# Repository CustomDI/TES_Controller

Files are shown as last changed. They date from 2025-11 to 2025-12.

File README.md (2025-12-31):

# TES Controller Serial Command Reference

This document describes every serial command exposed by the TES Controller
firmware found in `TES_Controller/TES_Controller.ino`. Use it as the definitive
reference when interacting with the board over a USB serial connection or when
building higher-level host tooling.

## Serial Session Basics

- **Port settings:** 115200 baud, 8 data bits, no parity, 1 stop bit, no flow
  control (115200 8N1).
- **Line endings:** Commands are terminated with a newline (`\n`) or carriage
  return + newline (`\r\n`). The command parser is case-insensitive for the
  top-level tokens (`LNA`, `TES`, `DAC`, `HELP`) but subcommand keywords should
  be supplied exactly as shown below.
- **Channel numbering:** Firmware expects one-based channel indices.
  - TES channels: `1` – `12`
  - LNA channels: `1` – `2`
- **Targets:** Whenever a command requires a LNA target path, use literal
  `GATE` or `DRAIN`.

## Response Format

Every command returns a YAML packet terminated by a blank line. Successful
operations use:

```yaml
---
status: ok
result:
  command: <NAME>
  ... additional key/value data ...
```

Failures (invalid parameters, I²C errors, etc.) use:

```yaml
---
status: error
result:
  error: "<SYMBOLIC_ERROR>"
  code: <numeric_status>
  message: "<human readable context>"
```

Keys and numeric ranges mentioned below mirror the firmware exactly.

## Command Tree Overview

| Top-Level | Syntax Skeleton | Purpose |
|---|---|---|
| `HELP` | `HELP` | List every available command and subcommand. |
| `DAC`  | `DAC <SUBCOMMAND> [...]` | Control the base flux-ramp DAC. |
| `LNA`  | `LNA <channel> <GATE\|DRAIN> <SUBCOMMAND> [...]` | Inspect or tune LNA DACs and telemetry. |
| `TES`  | `TES <channel> <SUBCOMMAND> [...]` | Inspect or tune TES drive outputs and telemetry. |

The sections below expand each subcommand, including argument ranges and the
keys returned in `result`.

## HELP

```
HELP
```

Prints a tree of all commands and their brief descriptions. No YAML payload is
returned; the output is plain text generated by the StaticSerialCommands
library.

## DAC Commands

Top-level syntax: `DAC <SUBCOMMAND> [...]`

| Subcommand | Syntax | Description | Response keys |
|---|---|---|---|
| `SET` | `DAC SET <value>` | Write channel A of the MCP4728 flux-ramp DAC. Valid `value` range is `0` – `1024`; this value is offset to a valid range. | `command: "DAC_SET"`, `value` (echo), `message` |
| `GET` | `DAC GET` | Read the current value programmed into channel A. | `command: "DAC_GET"`, `value`, `message` |

## LNA Commands

Top-level syntax: `LNA <channel> <GATE|DRAIN> <SUBCOMMAND> [...]`

- `channel`: integral, `1` – `2`
- `target`: literal `GATE` or `DRAIN`

| Subcommand | Syntax | Description | Response keys |
|---|---|---|---|
| `GET` | `LNA <ch> <target> GET` | Aggregate status dump of the selected path. | `command: "LNA_GET"`, `channel`, `target`, `dac_value`, `enabled`, `shunt_mV`, `bus_V`, `current_mA`, `power_mW` |
| `ENABLE` | `LNA <ch> <target> ENABLE` | Assert the enable line. | `command: "LNA_ENABLE"`, `channel`, `target`, `enabled: "true"` |
| `DISABLE` | `LNA <ch> <target> DISABLE` | De-assert the enable line. | `command: "LNA_DISABLE"`, `channel`, `target`, `enabled` (currently returns the string `"true"`; treat the command success as authoritative) |
| `SETMA` | `LNA <ch> <target> SETMA <current_mA>` | Closed-loop search to achieve the requested current. `current_mA` range: `0` – `64`. | `command: "LNA_SET"`, `channel`, `target`, `current_mA`, `dac_value` |
| `SETV` | `LNA <ch> <target> SETV <voltage_V>` | Closed-loop search to achieve the requested voltage. Range: `0` – `5` volts. | `command: "LNA_SET"`, `channel`, `target`, `voltage_V`, `dac_value` |
| `SETDAC` | `LNA <ch> <target> SETDAC <raw>` | Write a raw 12-bit DAC code (0 – 4095). | `command: "LNA_SET"`, `channel`, `target`, `value` |
| `SHUNT` | `LNA <ch> <target> SHUNT` | Read the INA228 shunt voltage in millivolts. | `command: "LNA_SHUNT"`, `channel`, `target`, `shunt_mV` |
| `BUS` | `LNA <ch> <target> BUS` | Read the bus voltage in volts. | `command: "LNA_BUS"`, `channel`, `target`, `bus_V` |
| `CURRENT` | `LNA <ch> <target> CURRENT` | Read the calculated current in milliamps. | `command: "LNA_CURRENT"`, `channel`, `target`, `current_mA` |
| `POWER` | `LNA <ch> <target> POWER` | Read the calculated power in milliwatts. | `command: "LNA_POWER"`, `channel`, `target`, `power_mW` |

Errors during any LNA operation return an `error` symbol such as
`"LNA_SET_ERROR"`, `"LNA_BUS_READ_ERROR"`, etc., along with the low-level I²C
status code (`code`).

## TES Commands

Top-level syntax: `TES <channel> <SUBCOMMAND> [...]`

- `channel`: integral, `1` – `12`

| Subcommand | Syntax | Description | Response keys |
|---|---|---|---|
| `GET` | `TES <ch> GET` | Aggregate status dump of the TES channel. | `command: "TES_GET"`, `channel`, `enabled`, `tca_bits`, `shunt_mV`, `bus_V`, `current_mA`, `power_mW` |
| `ENABLE` | `TES <ch> ENABLE` | Enable the TES output stage. | `command: "TES_ENABLE"`, `channel`, `enabled: "true"` |
| `DISABLE` | `TES <ch> DISABLE` | Disable the TES output stage. | `command: "TES_DISABLE"`, `channel`, `enabled: "false"` |
| `SET` | `TES <ch> SET <current_mA>` | Closed-loop current search (0 – 20 mA). Returns the final DAC state used. | `command: "TES_SET"`, `channel`, `current_mA` (achieved), `tca_bits` |
| `SETINT` | `TES <ch> SETINT <bits>` | Write raw 20-bit TCA output as an integer (`0` – `0xFFFFF`). | `command: "TES_SETINT"`, `channel`, `tca_bits` |
| `SETHEX` | `TES <ch> SETHEX <hex_value>` | Write raw 20-bit TCA output in hexadecimal (`00000` – `FFFFF`). | `command: "TES_SETHEX"`, `channel`, `tca_bits` |
| `BIT` | `TES <ch> BIT` | Read the current TCA output state. | `command: "TES_BITS"`, `channel`, `tca_bits` |
| `INC` | `TES <ch> INC <delta>` | Increase the TCA output by `delta` counts (0 – `0xFFFFF`). | `command: "TES_INC"`, `channel`, `delta`, `tca_bits` |
| `DEC` | `TES <ch> DEC <delta>` | Decrease the TCA output by `delta` counts. | `command: "TES_DEC"`, `channel`, `delta`, `tca_bits` |
| `SHUNT` | `TES <ch> SHUNT` | Measure shunt voltage (mV). | `command: "TES_SHUNT"`, `channel`, `shunt_mV` |
| `BUS` | `TES <ch> BUS` | Measure bus voltage (V). | `command: "TES_BUS"`, `channel`, `bus_V` |
| `CURRENT` | `TES <ch> CURRENT` | Measure TES current (mA). | `command: "TES_CURRENT"`, `channel`, `current_mA` |
| `POWER` | `TES <ch> POWER` | Measure TES power (mW). | `command: "TES_POWER"`, `channel`, `power_mW` |

All TES error responses follow the same structure with symbols like
`"TES_SET_CURRENT_ERROR"`, `"TES_TCA_READ_ERROR"`, etc.

## Notes & Tips

- **Search-based setters:** `LNA SETMA`, `LNA SETV`, and `TES SET` perform
  iterative searches using the underlying driver convenience routines. The
  returned `current_mA`, `voltage_V`, or `tca_bits` represent the post-search
  state actually achieved.
- **Raw DAC writes:** `SETDAC`, `SETINT`, and `SETHEX` bypass any search logic
  and immediately write the specified code. Take care not to exceed the valid
  ranges—values outside the ranges listed above are rejected with
  `status: error`.
- **Telemetry units:**
  - Shunt voltages are reported in millivolts (`mV`).
  - Bus voltages are reported in volts (`V`).
  - Currents are reported in milliamps (`mA`).
  - Powers are reported in milliwatts (`mW`).
- **Error codes:** The numeric `code` field in an error response comes directly
  from the driver status return (typically an I²C error byte). A non-zero code
  indicates the call did not reach the requested hardware state.

With this reference you can script direct interactions with the firmware, build
custom tooling, or simply verify that higher-level software layers send the
expected traffic.

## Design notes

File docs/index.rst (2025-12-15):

TES Controller Documentation
============================

Welcome to the TES Controller Python client documentation!

The TES Controller is a Python interface for controlling Transition Edge Sensor
(TES) and Low Noise Amplifier (LNA) hardware via serial communication.

.. toctree::
   :maxdepth: 2
   :caption: Contents:

   installation
   getting-started
   usage
   examples
   api
   hardware-guide

Key Features
------------

- **Simple API**: High-level helpers for TES, LNA, and flux ramp control
- **Flexible Channel Selection**: Address individual channels or batches with one call
- **Typed Interfaces**: Rich type hints for IDE autocomplete and static analysis
- **Comprehensive Error Handling**: Deterministic `CommandError` hierarchy for driver faults
- **Config Driven**: Optional YAML configuration keeps serial parameters out of code
- **Context Manager Support**: Clean resource management with ``with`` statements

Quick Start
-----------

.. code-block:: python

   from tes_controller import DeviceController

   # Load settings from YAML
   with DeviceController.from_config('python/config.yaml') as ctrl:
      ctrl.tes_enable(channel=[1, 2, 3])
      ctrl.tes_set_current(channel=[1, 2, 3], current_mA=[5.0, 4.5, 4.0])
      reading = ctrl.tes_get_all(channel=1)
      print(reading)

   # Or construct manually when you need to override serial defaults
   ctrl = DeviceController(port='/dev/ttyACM0', baud=115200, timeout=1.0)
   try:
      ctrl.tes_set_current(current_mA=5.0)
   finally:
      ctrl.close()

Indices and tables
==================

* :ref:`genindex`
* :ref:`modindex`
* :ref:`search`

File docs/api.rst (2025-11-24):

API Reference
=============

Top-level Package
-----------------

.. automodule:: tes_controller
   :members:
   :undoc-members:
   :show-inheritance:

Device Controller
-----------------

.. automodule:: tes_controller.controller
   :members:
   :undoc-members:
   :show-inheritance:
   :exclude-members: DeviceController

.. autoclass:: tes_controller.controller.DeviceController
   :members:
   :show-inheritance:

Drivers
-------

.. automodule:: tes_controller.drivers
   :members:
   :undoc-members:
   :show-inheritance:

Serial Client
-------------

.. automodule:: tes_controller.serial_client
   :members:
   :undoc-members:
   :show-inheritance:

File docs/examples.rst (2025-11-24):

Examples
========

The snippets below illustrate complete, runnable patterns built on top of the
high-level :class:`tes_controller.controller.DeviceController` API.

Basic Example
-------------

.. code-block:: python

   from tes_controller import DeviceController
   from tes_controller.drivers import CommandError

   with DeviceController.from_config('python/config.yaml') as ctrl:
       try:
           reading = ctrl.tes_get_all(channel=1)
           print(f"Channel 1 state: {reading}")

           ctrl.tes_set_current(channel=1, current_mA=5.0)
           ctrl.tes_enable(channel=1)
       except CommandError as exc:
           print(f"Hardware command failed: {exc}")

Multi-Channel Operations
------------------------

.. code-block:: python

   from tes_controller import DeviceController

   with DeviceController.from_config('python/config.yaml') as ctrl:
       all_data = ctrl.tes_get_all()
       for index, data in enumerate(all_data, start=1):
           print(f"Channel {index}: {data}")

       ctrl.tes_set_current(current_mA=5.0)

       ctrl.tes_set_current(
           current_mA=[1.0, 2.0, 3.0, 4.0, 5.0, 6.0]
       )

       ctrl.tes_enable(channel=[1, 3, 5])

Current Sweep
-------------

.. code-block:: python

   import time
   from tes_controller import DeviceController

   with DeviceController.from_config('python/config.yaml') as ctrl:
       channel = 1
       for target in [0.5, 1.0, 1.5, 2.0, 2.5]:
           ctrl.tes_set_current(channel=channel, current_mA=target)
           time.sleep(0.1)
           readback = ctrl.tes_get_current(channel=channel)
           print(f"Commanded {target:.2f} mA -> {readback.get('current_mA', 'N/A')} mA")

Batch Configuration
-------------------

.. code-block:: python

   from tes_controller import DeviceController

   configuration = {
       1: {"current_mA": 5.0, "enabled": True},
       2: {"current_mA": 3.5, "enabled": True},
       3: {"current_mA": 4.2, "enabled": False},
       4: {"current_mA": 6.1, "enabled": True},
       5: {"current_mA": 2.8, "enabled": True},
       6: {"current_mA": 5.5, "enabled": False},
   }

   with DeviceController.from_config('python/config.yaml') as ctrl:
       for channel, settings in configuration.items():
           ctrl.tes_set_current(channel=channel, current_mA=settings["current_mA"])
           if settings["enabled"]:
               ctrl.tes_enable(channel=channel)
           else:
               ctrl.tes_disable(channel=channel)

       for channel in configuration:
           print(f"Channel {channel}: {ctrl.tes_get_all(channel=channel)}")

LNA Configuration
-----------------

.. code-block:: python

   from tes_controller import DeviceController

   with DeviceController.from_config('python/config.yaml') as ctrl:
       ctrl.lna_set_dac(target='GATE', value=[0x4000, 0x4500, 0x5000, 0x5500, 0x6000, 0x6500])
       ctrl.lna_set_dac(channel=[1, 2, 3], target='DRAIN', value=0x8000)

       ctrl.lna_enable(target='GATE')
       ctrl.lna_enable(channel=[1, 2, 3], target='DRAIN')

       for channel in range(1, 7):
           gate = ctrl.lna_get_all(channel=channel, target='GATE')
           drain = ctrl.lna_get_all(channel=channel, target='DRAIN')
           print(f"Channel {channel}: gate={gate} drain={drain}")

       ctrl.lna_set_voltage(channel=1, target='GATE', voltage_V=1.2)
       ctrl.lna_set_current(target='GATE', current_mA=[0.5, 1.0, 1.5, 2.0, 2.5, 3.0])

Flux Ramp DAC
-------------

.. code-block:: python

   from tes_controller import DeviceController

   with DeviceController.from_config('python/config.yaml') as ctrl:
       ctrl.flux_ramp_set(0x8000)
       print(ctrl.flux_ramp_get())

Data Acquisition
----------------

.. code-block:: python

   import csv
   import time
   from tes_controller import DeviceController

   with DeviceController.from_config('python/config.yaml') as ctrl:
       ctrl.tes_enable()
       ctrl.tes_set_current(current_mA=5.0)

       sample_rate_hz = 10
       duration_sec = 5
       interval = 1.0 / sample_rate_hz

       with open('tes_data.csv', 'w', newline='') as handle:
           writer = csv.writer(handle)
           header = ['time_s']
           header.extend([f'ch{idx}_current_mA' for idx in range(1, ctrl.num_tes + 1)])
           header.extend([f'ch{idx}_power_mW' for idx in range(1, ctrl.num_tes + 1)])
           writer.writerow(header)

           start = time.time()
           while time.time() - start < duration_sec:
               elapsed = time.time() - start
               currents = ctrl.tes_get_current()
               powers = ctrl.tes_get_power()
               row = [elapsed]
               row.extend([entry.get('current_mA', 0.0) for entry in currents])
               row.extend([entry.get('power_mW', 0.0) for entry in powers])
               writer.writerow(row)
               time.sleep(interval)

Robust Error Handling
---------------------

.. code-block:: python

   import time
   from tes_controller import DeviceController
   from tes_controller.drivers import CommandError

   def safe_set_current(ctrl, channel, current_mA, attempts=3):
       for attempt in range(1, attempts + 1):
           try:
               ctrl.tes_set_current(channel=channel, current_mA=current_mA)
               time.sleep(0.1)
               actual = ctrl.tes_get_current(channel=channel)
               print(f"Channel {channel}: target {current_mA} mA -> actual {actual.get('current_mA', 'N/A')} mA")
               return True
           except CommandError as exc:
               print(f"Attempt {attempt}/{attempts} failed: {exc}")
       return False

   with DeviceController.from_config('python/config.yaml') as ctrl:
       for channel in range(1, ctrl.num_tes + 1):
           safe_set_current(ctrl, channel, current_mA=5.0)

Complete Workflow Script
------------------------

.. code-block:: python

   import argparse
   import time
   from tes_controller import DeviceController
   from tes_controller.drivers import CommandError

   def initialize(ctrl):
       ctrl.tes_disable()
       ctrl.tes_set_current(current_mA=0.0)
       ctrl.lna_disable(target='GATE')
       ctrl.lna_disable(target='DRAIN')
       ctrl.lna_set_dac(target='GATE', value=0x0000)
       ctrl.lna_set_dac(target='DRAIN', value=0x0000)

   def run_profile(ctrl, profile):
       ctrl.tes_set_current(current_mA=profile['tes_current'])
       ctrl.tes_enable(channel=profile['tes_channels'])
       ctrl.lna_set_dac(target='GATE', value=profile['lna_gate'])
       ctrl.lna_enable(target='GATE')
       time.sleep(profile.get('settling_time', 1.0))
       return ctrl.tes_get_all()

   def shutdown(ctrl):
       ctrl.tes_disable()
       ctrl.lna_disable(target='GATE')
       ctrl.lna_disable(target='DRAIN')

   def main():
       parser = argparse.ArgumentParser(description='TES Controller workflow')
       parser.add_argument('--config', default='python/config.yaml')
       args = parser.parse_args()

       try:
           with DeviceController.from_config(args.config) as ctrl:
               initialize(ctrl)
               profiles = [
                   {
                       'tes_current': 5.0,
                       'tes_channels': [1, 2, 3],
                       'lna_gate': 0x8000,
                       'settling_time': 1.0,
                   },
                   {
                       'tes_current': 7.5,
                       'tes_channels': [4, 5, 6],
                       'lna_gate': 0xA000,
                       'settling_time': 1.0,
                   },
               ]

               for index, profile in enumerate(profiles, start=1):
                   print(f"\n=== Profile {index}/{len(profiles)} ===")
                   result = run_profile(ctrl, profile)
                   print(result)

               shutdown(ctrl)
       except CommandError as exc:
           print(f"Hardware error: {exc}")
       except Exception as exc:
           print(f"Unexpected error: {exc}")

   if __name__ == '__main__':
       main()

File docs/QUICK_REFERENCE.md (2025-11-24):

# TES Controller Quick Reference

## Installation

```bash
pip install -r python/requirements.txt
cp python/config_example.yaml python/config.yaml
```

## Basic Pattern

```python
from tes_controller import DeviceController

with DeviceController.from_config('python/config.yaml') as ctrl:
    ctrl.tes_enable(channel=1)
    ctrl.tes_set_current(channel=1, current_mA=5.0)
    print(ctrl.tes_get_all(channel=1))
```

## Channel Selection Cheatsheet

| Call | Description | Return Type |
|---|---|---|
| `ctrl.tes_get_all(channel=1)` | Single channel | `dict` |
| `ctrl.tes_get_all(channel=[1, 3, 5])` | Subset of channels | `list[dict]` |
| `ctrl.tes_get_all()` | All channels | `list[dict]` |
| `ctrl.tes_set_current(current_mA=5.0)` | Same value on all channels | `list[dict]` |
| `ctrl.tes_set_current(channel=[1, 3], current_mA=[1.0, 2.0])` | Pair channel list with value list | `list[dict]` |

## TES Helpers

```python
ctrl.tes_set_current(channel=1, current_mA=5.0)
ctrl.tes_inc_current(channel=1, delta=100)
ctrl.tes_dec_current(channel=1, delta=50)
ctrl.tes_set_bits(channel=1, value=0x80000)
ctrl.tes_get_current(channel=1)
ctrl.tes_get_power(channel=1)
```

## LNA Helpers

Always supply `target='GATE'` or `target='DRAIN'`.

```python
ctrl.lna_set_dac(channel=1, target='GATE', value=0x8000)
ctrl.lna_set_dac(channel=1, target='GATE', value=1.2)    # physical units
ctrl.lna_enable(target='GATE')
ctrl.lna_disable(channel=[1, 2, 3], target='GATE')
ctrl.lna_set_voltage(channel=1, target='GATE', voltage_V=1.2)
ctrl.lna_set_current(target='GATE', current_mA=[0.5, 1.0, 1.5, 2.0, 2.5, 3.0])
```

## Flux Ramp DAC

```python
ctrl.flux_ramp_set(0x8000)
ctrl.flux_ramp_get()
```

## Error Handling

```python
from tes_controller.drivers import CommandError

try:
    ctrl.tes_set_current(channel=1, current_mA=5.0)
except CommandError as exc:
    print(f"Hardware command failed: {exc}")
```

## CLI Snippets

```bash
# Build documentation
make -C docs html

# Live rebuild during authoring
sphinx-autobuild docs docs/_build/html
```

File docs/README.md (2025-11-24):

# TES Controller Documentation

This directory contains the Sphinx authoring environment for the TES Controller
project.

## 📚 Contents

### reStructuredText pages
- `index.rst` – Landing page and master ToC
- `installation.rst` – Platform-specific setup
- `getting-started.rst` – Day-one workflow guide
- `usage.rst` – Recipes and quick snippets
- `examples.rst` – End-to-end scripts
- `api.rst` – Autogenerated API reference

### Helper docs
- `README.md` – You are here
- `DOCUMENTATION_SETUP.md` – Deployment walkthrough
- `QUICK_REFERENCE.md` – One-page API cheat sheet

### Configuration & tooling
- `conf.py` – Sphinx configuration (autodoc, napoleon, type hints)
- `requirements.txt` – Doc build dependencies
- `Makefile` / `make.bat` – Build helpers (Unix/Windows)
- `_static/` – Custom static assets
- `.nojekyll` – Ensures nested directories are served by GitHub Pages

## 🚀 Build Locally

```bash
pip install -r docs/requirements.txt
make -C docs html
```

Open `docs/_build/html/index.html` in your browser when the build finishes.

### Clean & rebuild

```bash
make -C docs clean html
```

### Live reload during authoring

```bash
pip install sphinx-autobuild
sphinx-autobuild docs docs/_build/html
```

## 🌐 Publish Options

### GitHub Pages
1. Enable Pages for the repository and choose the `docs/` folder as the source.
2. Copy `docs/_build/html` into `docs/` (or automate via GitHub Actions).
3. Commit and push – GitHub Pages redeploys automatically.

### Read the Docs (optional)
1. Log in at <https://readthedocs.org/> with your GitHub account.
2. Import the repository; RTD auto-detects `docs/conf.py`.
3. Trigger a build to publish at `https://<project>.readthedocs.io/`.

## 🛠️ Updating Content
- Add new pages → create `docs/new-page.rst`, reference it in `index.rst`, rebuild.
- Refresh API docs → update Python docstrings and rerun `make -C docs html`.
- Ship new examples → edit `docs/examples.rst` and ensure scripts execute cleanly.

## ❗ Troubleshooting

| Issue | Resolution |
|---|---|
| `ModuleNotFoundError: tes_controller` | Run builds from repo root; confirm `conf.py` manipulates `sys.path`. |
| Missing CSS/JS on GitHub Pages | Ensure `.nojekyll` is present and assets were copied. |
| Sphinx warnings | Run `make -C docs clean html` and address reported issues. |

## 📎 Resources
- [Sphinx documentation](https://www.sphinx-doc.org/)
- [Read the Docs guide](https://docs.readthedocs.io/)
- [reStructuredText primer](https://www.sphinx-doc.org/en/master/usage/restructuredtext/basics.html)

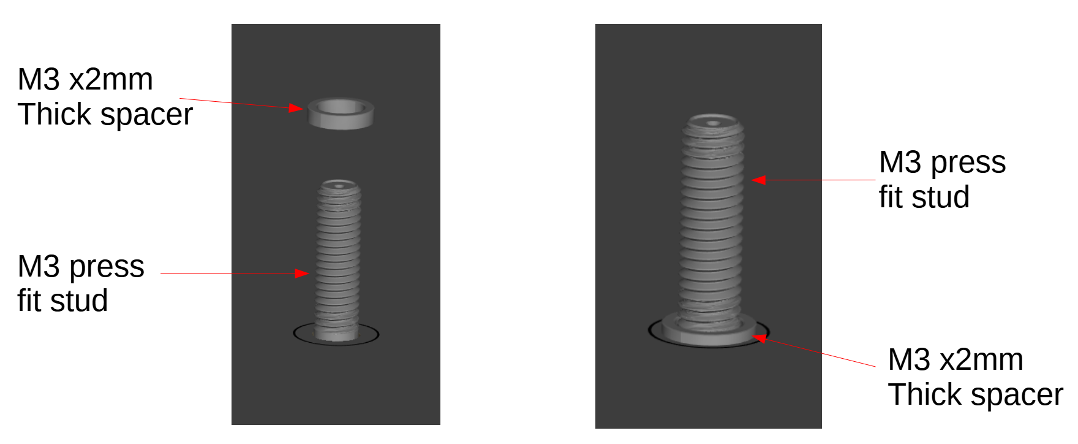
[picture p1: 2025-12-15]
docs/_static/hardware-pictures/spacers.png

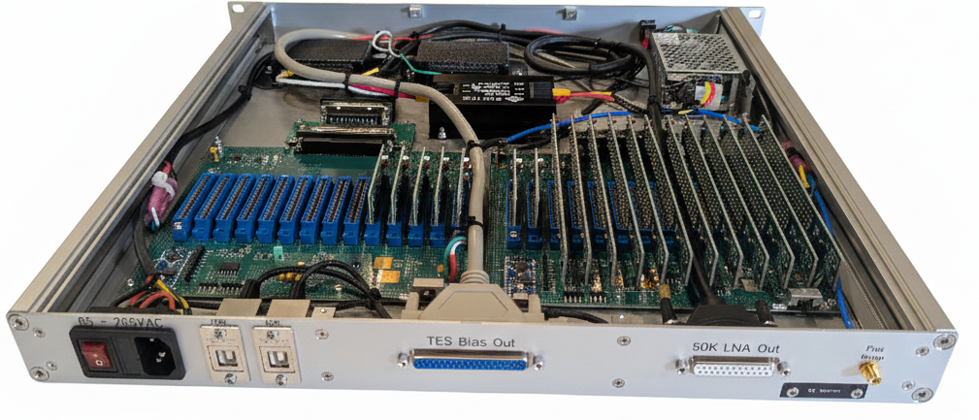
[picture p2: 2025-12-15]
docs/_static/hardware-pictures/TES_Bias_System_side_2.png

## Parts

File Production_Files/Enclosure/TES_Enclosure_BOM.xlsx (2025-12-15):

Vendor | Link | Category | Descriptor | Part # | Price | Quantity | # Spare(s) | Total Price | Note
Front Panel Express | Contact and Pay | Payment | Front/Back panel/Housing profile | N/A |  | 1 | 0 | $0.00
SendCutSend | https://invoice.sendcutsend.com/urhwne3jqfz8 | Payment Link | Rest of enclosure | N/A | $373.56 | 1 | 0 | $373.56
McMaster | https://www.mcmaster.com/9290T12/ | Electronic Hardware | Bus bar | 9290T12 | $27.11 | 2 | 0 | $54.22
McMaster | https://www.mcmaster.com/9290T25/ | Electronic Hardware | Bus bar cover | 9290T25 | $19.80 | 2 | 0 | $39.60
Digikey | https://www.digikey.com/en/products/detail/tdk-lambda/CUT35-522-A/6874069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 | Electronic Hardware | Power Supply | CUT35-522/A | $50.41 | 1 | 0 | $50.41
Digikey | https://www.digikey.com/en/products/detail/cui-inc/VFM-15C/2294930 | Electronic Hardware | Line Filter | VFM-15C | $47.83 | 1 | 0 | $47.83
Amazon | https://www.amazon.com/Kentek-Extension-Connector-Printer-Network/dp/B07KVC9C21 | Cable | DSUB 37 M to F | KT-DB37-MF-3FT | $16.74 | 1 | 1 | $33.48
Amazon | https://www.amazon.com/Female-Extension-Different-Colored-double-shielded/dp/B092QV8DGK | Cable | DSUB 25 M to F |  | $11.99 | 1 | 1 | $23.98
Amazon | https://www.amazon.com/Durable-Braided-Android-Charging-Samsung/dp/B09XK4JDBJ | Cable | Right angle 1ft micro usb (3 pack) | 1Ft-RA-MicroUSB-3P | $7.99 | 1 | 0 | $7.99
Digikey | https://www.digikey.com/en/products/detail/mini-circuits/086-18SBSMR/20526752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 | Cable | Flux ramp SMA cable | 086-18SBSMR+ | $31.03 | 1 | 0 | $31.03
Amazon | https://www.amazon.com/C2G-03130-Universal-Power-Cord/dp/B0000510ZO | Cable | 3 prong power cable |  | $4.95 | 1 | 0 | $4.95
Amazon | https://www.amazon.com/gp/product/B0899V8XH8?smid=A2ZDGCOOU4F0SF&psc=1 | Enclosure Fittings | AC Fused Socket with Switch (Rear Panel) | SM487-C14-Switch-2PCS | $16.99 | 1 | 0 | $16.99
Digikey | https://www.digikey.com/en/products/detail/l-com/ECF504-BA/21288387 | Enclosure Fittings | Adapter Connector USB-B (USB TYPE-B), Receptacle To USB-A (USB TYPE-A), Receptacle Panel Mount, Flange | ECF504-BA | $4.86 | 2 | 1 | $14.58
Digikey | https://www.digikey.com/en/products/detail/cit-relay-and-switch/RA1122XCG/12418854 | Enclosure Fittings | Rocker Switch SPST 15A (AC) 125 V Panel Mount, Snap-In | RA1122XCG | $1.66 | 1 | 1 | $3.32
Mcmaster | https://www.mcmaster.com/91115A505/ | Enclosure Fittings | DSUB standoffs for FP | 91115A505 | $1.97 | 4 | 2 | $11.82 | This is optional. This connection between the DSUB cables on either side of the panel should be sturdy enough . The standoff listed here is our best guess at the length to mate
Mcmaster | https://www.mcmaster.com/94868A038/ | Hardware | Busbar nuts | 94868A038 | $1.70 | 4 | 2 | $10.20
Mcmaster | https://www.mcmaster.com/97258A101/ | Hardware | M3 square nuts (50 pack). Slide these into corner extrusions to secure bottom and top panels to the sides | 97258A101 | $7.14 | 1 | 0 | $7.14
Isel-usa | https://www.isel-us.com/enclosure-profiles/16x18-extrusion-enclosure-corner-profile | Enclosure | 16x18-extrusion-enclosure-corner-profile. Enclosure corners. Need to be cut to equal the height of the panel (445mm) | G123020_1000 |  |  |  | $0.00
Mcmaster | https://www.mcmaster.com/90116a147/ | Hardware | Busbar cover screws: M3 4mm | 90116A147 | $15.71 | 1 |  | $15.71
Amazon | https://www.amazon.com/Swpeet-Aluminum-Assortment-Standoff-Unthreaded/dp/B0DNF9ZYY6 | Hardware | spacers for mounting plate | B0DNF9ZYY6 | $17.99 | 2 |  | $35.98
Front Panel Express | https://shop.frontpanelexpress.com/#Products | Hardware | L brackets for lid and bottom panel (12 pack) | GGWS0113 | $35.00 | 1 | 0 | $35.00 | Only 8 are necessary
Mcmaster | https://www.mcmaster.com/95844A627/ | Hardware | M4.8 machine screws for mounting housing profiles into Front and back panels | 95844A627 | $7.25 | 1 | 0 | $7.25
Mcmaster | https://www.mcmaster.com/92000A114/ | Hardware | M3 x 5mm pan head screws for L-brackets, some enclosure fittings and lid | 92000A114 | $5.45 | 1 |  | $5.45
Mcmaster | https://www.mcmaster.com/90576A102/ | Hardware | M3 locknuts for top of mounting plate | 90576A102 | $5.08 | 1 |  | $5.08
Amazon | https://a.co/d/gfr9Ptf | Electronic Hardware | Electrical Insulating Adhesive Paper 200mm(7.9in) Width 3m Length 0.2mm Thickness Self Adhesive Battery Pack Insulator Gasket for 18650 21700 26650 Battery Pack, Green | B0CJHW8JVR | $14.99 | 1 |  | $14.99
Mcmaster | https://www.mcmaster.com/93115K871/ | Hardware | Enclosure feet
Digikey | https://www.digikey.com/en/products/detail/jst-sales-america-inc/VHR-5N/608627 | Cable | Connector for power supply to Line filter | VHR-5N | $0.14 | 1 |  | $0.14
Digikey | https://www.digikey.com/en/products/detail/jst-sales-america-inc/ASVHSVH16K305/6009483 | Cable | cable with pre-crimped fittings for VHR-5N connector (power supply) | ASVHSVH16K305 | $0.86 | 3 |  | $2.58
 |  |  |  |  |  |  |  | $0.00
 |  |  |  |  |  |  |  | $0.00
 |  |  |  |  |  |  |  | $0.00
 |  |  |  |  |  |  |  | $0.00
 |  |  |  |  |  |  |  | $0.00
 |  |  |  |  |  |  |  | $0.00
 |  |  |  |  |  |  |  | $0.00
 |  |  |  |  |  |  |  | $0.00
 |  |  |  |  |  |  |  | $0.00
 |  |  |  |  |  |  |  | $0.00
 |  |  |  |  |  |  |  | $0.00
 |  |  |  |  |  |  |  | $0.00
 |  |  |  |  |  |  |  | $0.00
 |  |  |  |  |  |  |  | $0.00
 |  |  |  |  |  |  |  | $0.00
 |  |  |  |  |  |  |  | $0.00
 |  |  |  |  |  |  |  | $0.00
 |  |  |  |  |  |  |  | $0.00
 |  |  |  |  |  |  |  | $0.00
 |  |  |  |  |  |  |  | $0.00
 |  |  |  |  |  |  |  | $0.00
 |  |  |  |  |  |  |  | $0.00
 |  |  |  |  |  |  |  | $0.00
 |  |  |  |  |  |  |  | $0.00
 |  |  |  |  |  |  |  | $0.00
 |  |  |  |  |  |  |  | $0.00
 |  |  |  |  |  |  |  | $0.00
 |  |  |  |  |  |  |  | $0.00

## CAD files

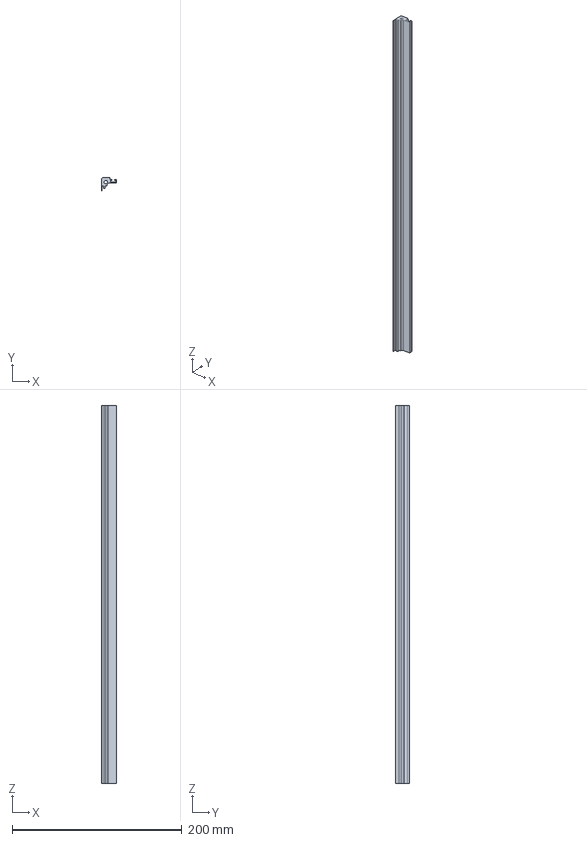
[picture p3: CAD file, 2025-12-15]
Production_Files/Enclosure/HousingProfile2_445mm.step
18.0 x 16.0 x 444.9 mm

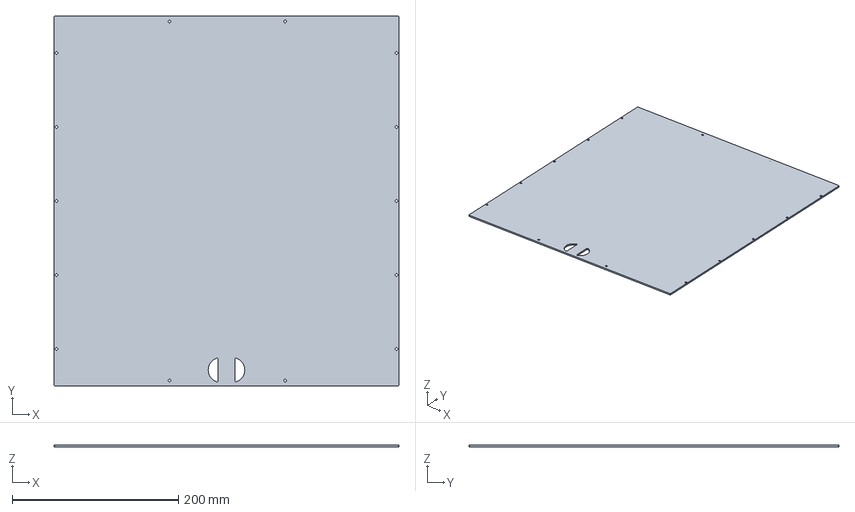
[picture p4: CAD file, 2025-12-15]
Production_Files/Enclosure/TESbias_Top.stp
415.0 x 445.0 x 2.50 mm

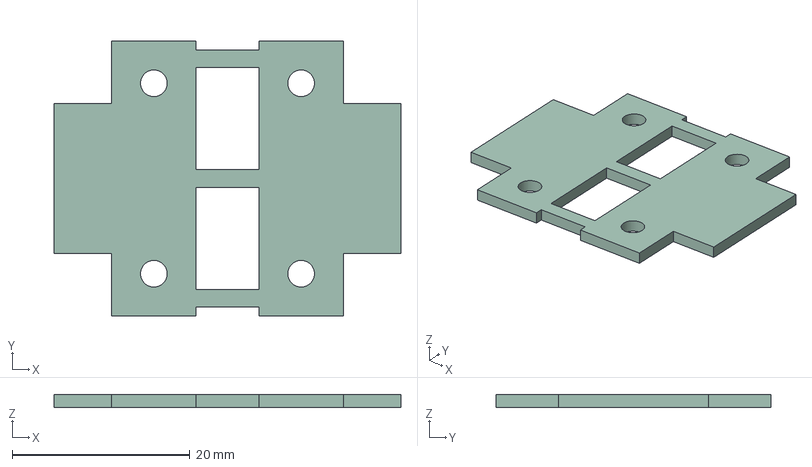
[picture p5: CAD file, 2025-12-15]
Production_Files/Enclosure/T-Bracket.step
39.1 x 30.9 x 1.51 mm

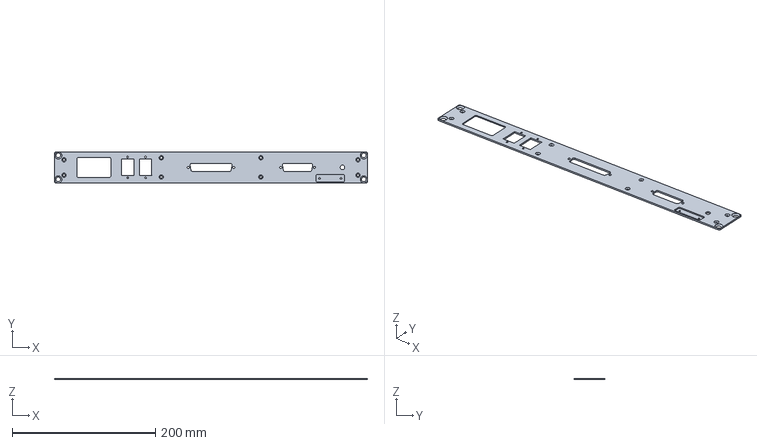
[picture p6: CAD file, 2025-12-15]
Production_Files/Enclosure/TESbias_Back.stp
437.0 x 43.9 x 2.00 mm

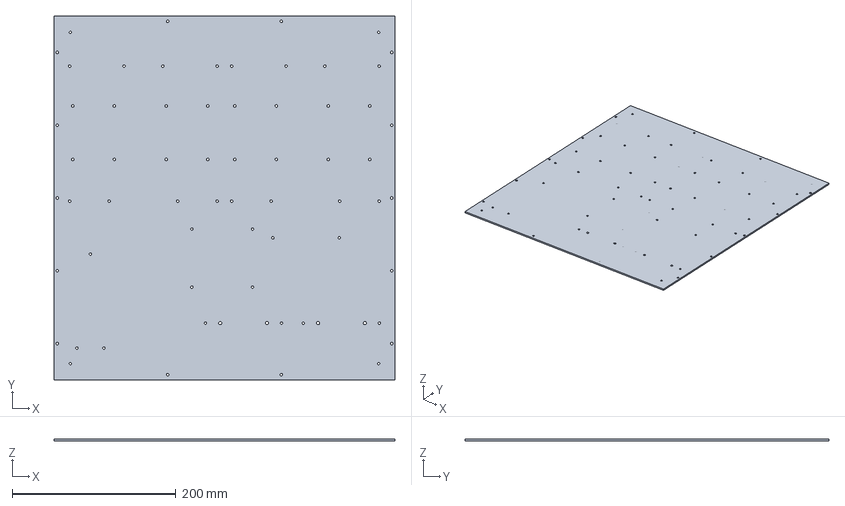
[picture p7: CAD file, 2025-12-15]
Production_Files/Enclosure/TESbias_Bottom_rev1.stp
417.0 x 445.0 x 2.50 mm

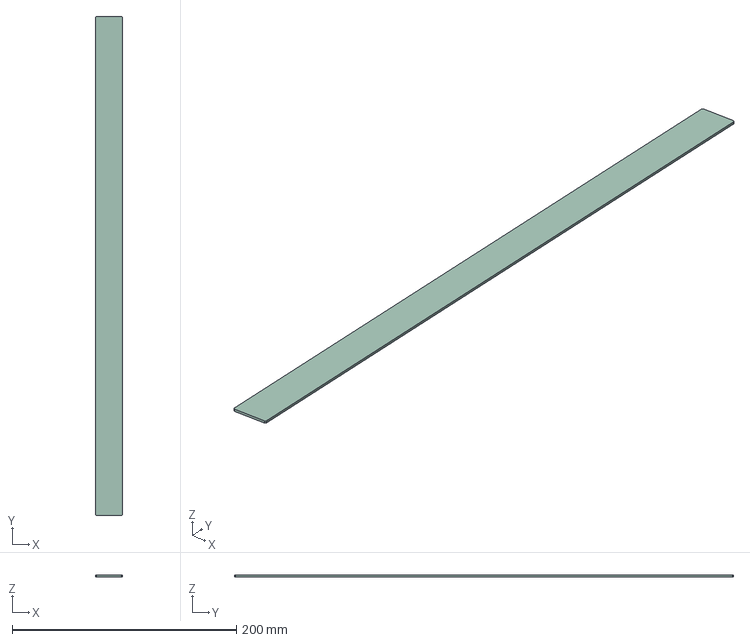
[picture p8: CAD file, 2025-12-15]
Production_Files/Enclosure/SidePanel_1U_445mm.step
23.9 x 445.0 x 1.51 mm

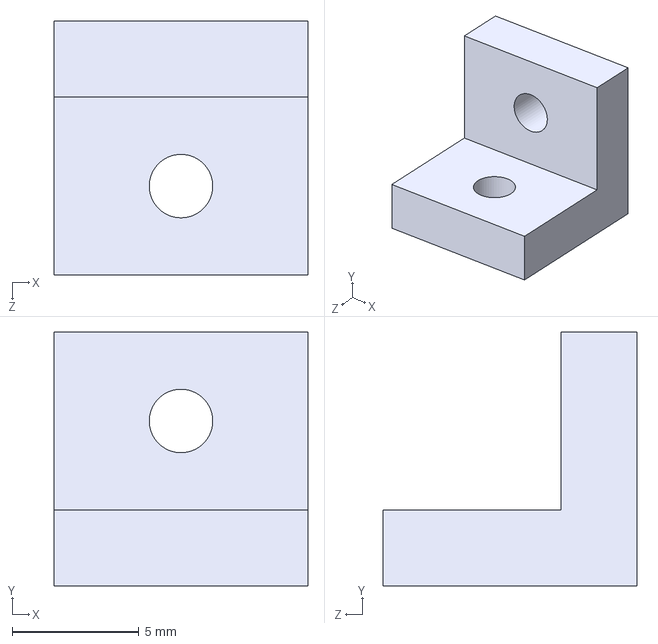
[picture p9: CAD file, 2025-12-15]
Production_Files/Enclosure/L-bracket.STEP
10.0 x 10.0 x 10.0 mm

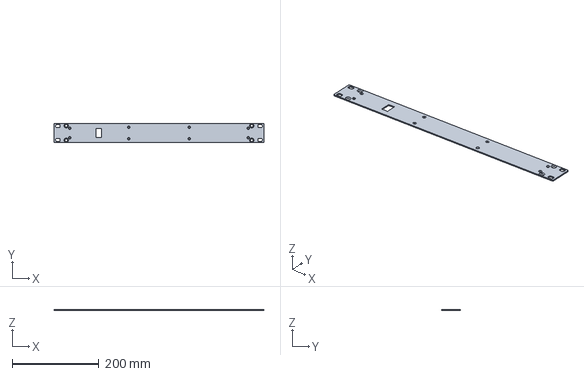
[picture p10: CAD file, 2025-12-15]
Production_Files/Enclosure/TESbias_Front.stp
483.0 x 43.9 x 2.00 mm

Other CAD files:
Production_Files/Enclosure/SidePanel_1U_445mm.dxf
Production_Files/Enclosure/T-Bracket.dxf
Production_Files/Enclosure/TESbias_Back.dxf
Production_Files/Enclosure/TESbias_Bottom_rev1.dxf
Production_Files/Enclosure/TESbias_Front.dxf
Production_Files/Enclosure/TESbias_Top.dxf

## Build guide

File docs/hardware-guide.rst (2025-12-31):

Hardware Guide
==============

This guide outlines the PCBs, hardware, and assembly of the 
TES Bias System. The production files for the enclosure can be 
found in the `Production_Files directory <https://github.com/CustomDI/TES_Controller/Production_Files>`__.

Printed Circuit Boards (PCBs)
-----------------------------

LNA Bias Card
~~~~~~~~~~~~~
Note that both bias cards are reversible. They can be placed in a card slot in either direction.
The LNA Bias card is capable of providing a positive voltage rail (0 to 4.95V)
for the drain of an LNA and negative voltage rail (-4.95 to 0V) for the gate of an LNA.
This is sufficient for both the 4K and 50K LNAs.

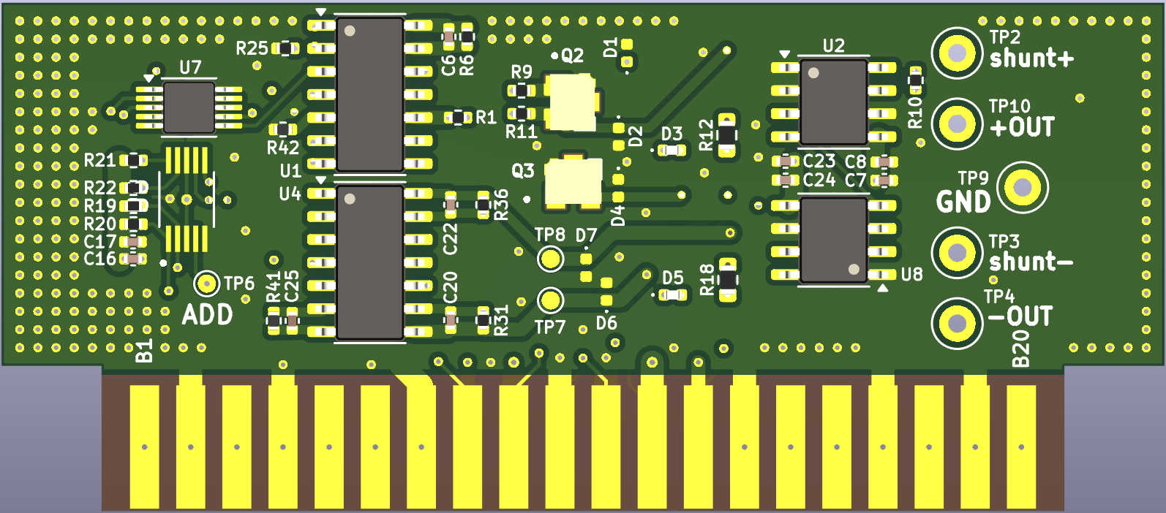
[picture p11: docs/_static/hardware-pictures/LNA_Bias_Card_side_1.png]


    LNA Bias Card Side 1.

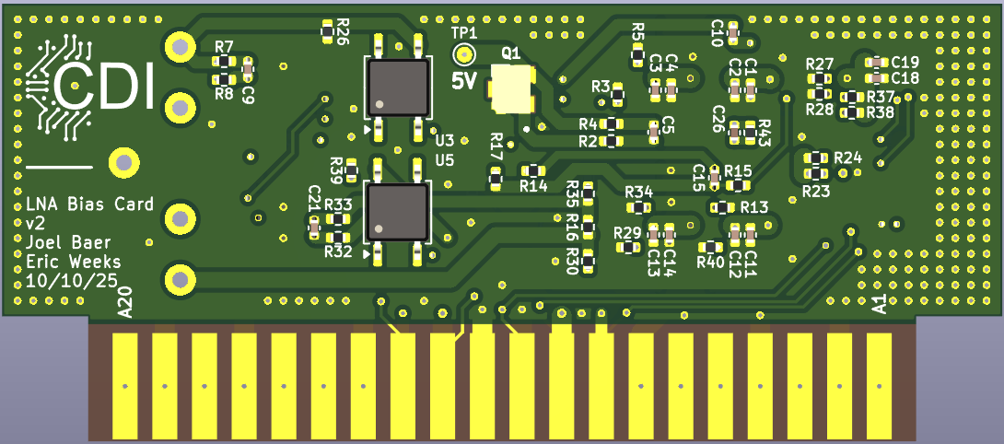
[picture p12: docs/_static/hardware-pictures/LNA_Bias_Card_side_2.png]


    LNA Bias Card Side 2.

TES Bias Card
~~~~~~~~~~~~~
The TES Bias Card is a 20 bit programmable resistor/voltage divider 
that provides current steps of 20nA.

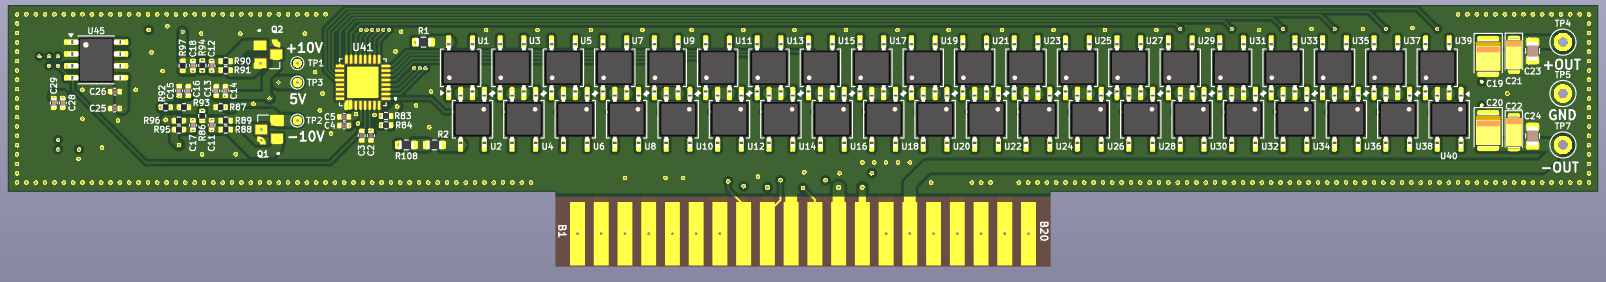
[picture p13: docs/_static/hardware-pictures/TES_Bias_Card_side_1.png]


    TES Bias Card Side 1.

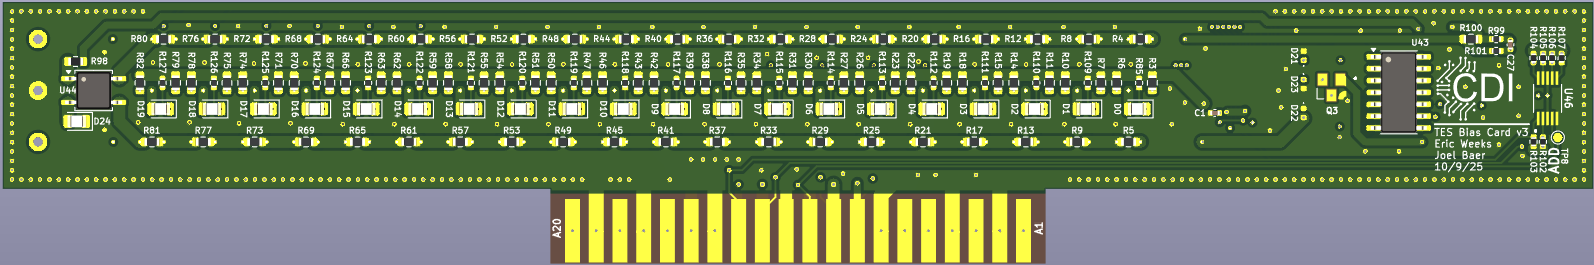
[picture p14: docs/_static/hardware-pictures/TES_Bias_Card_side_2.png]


    TES Bias Card Side 2.

DSUB Converter
~~~~~~~~~~~~~~

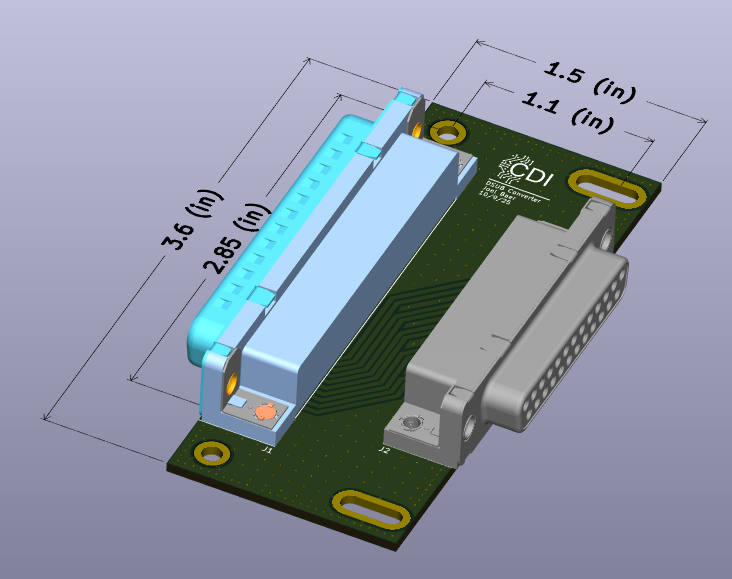
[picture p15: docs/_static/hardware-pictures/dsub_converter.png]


    DSUB converter board to for the 50K LNA board output. Converts 37 pin DSUB to a 25 pin DSUB.

Enclosure
---------

This section details how to assemble the enclosure, including the electronics within.
It's important to note that many of these pictures show a mounting plate sitting atop the 
bottom panel - the mounting plate is NOT in the final design. The 
production files will include bottom panel files only, no mounting plate.

Panel 1
~~~~~~~~~~~~

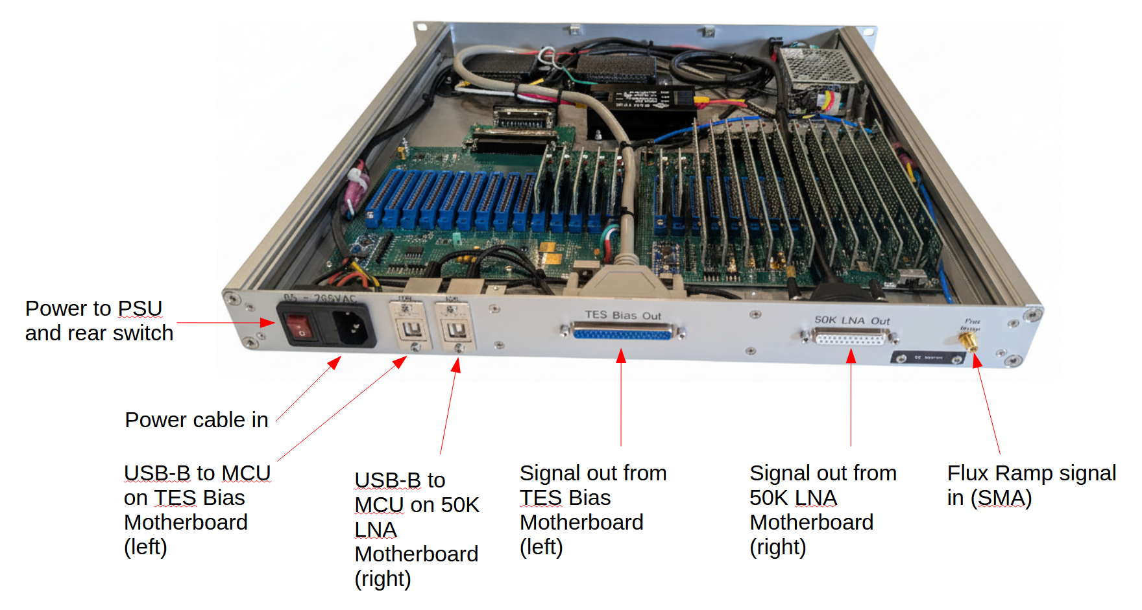
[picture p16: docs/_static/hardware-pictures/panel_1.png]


    Panel 1 contains all data ports and a power switch.

Panel 2
~~~~~~~~~~~~

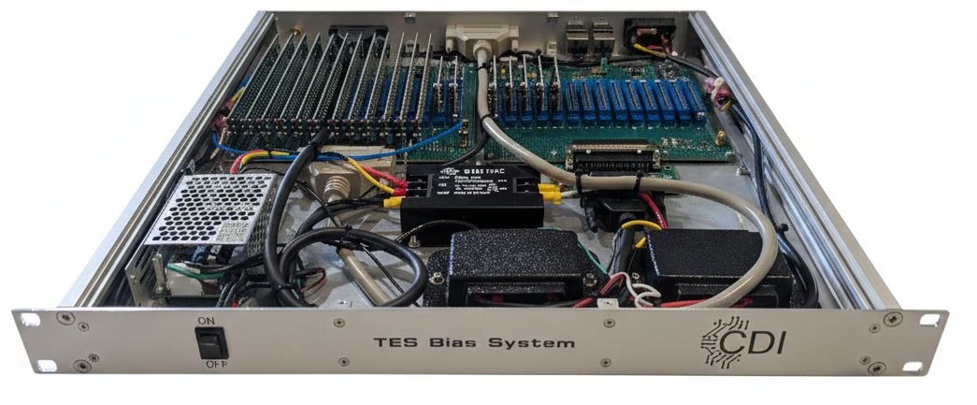
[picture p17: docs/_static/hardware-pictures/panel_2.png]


    Panel 2 only contains a power switch.

Bottom Panel
~~~~~~~~~~~~
The bottom panel should be manufactured with several types of press fit studs 
(see `Step 1`_):
M3x6mm, M3x10mm, M3x15mm and M4x10mm. If you want the bottom panel to lay truly flat
on a surface, countersink the 5 unthreaded M3 holes on the left and right of the panel,
and use flat head screws instead of pan head screws (M3x4mm). Be sure to countersink from
the side that does not have the studs sticking out. Reference the pictures below in Step 1
to determine the location of these holes (10 total). This guide will reference
the non-countersunk procedure.

Fully Assembled Enclosure
~~~~~~~~~~~~~~~~~~~~~~~~~

The TES Enclosure BOM lists every component needed to create a TES Bias System.

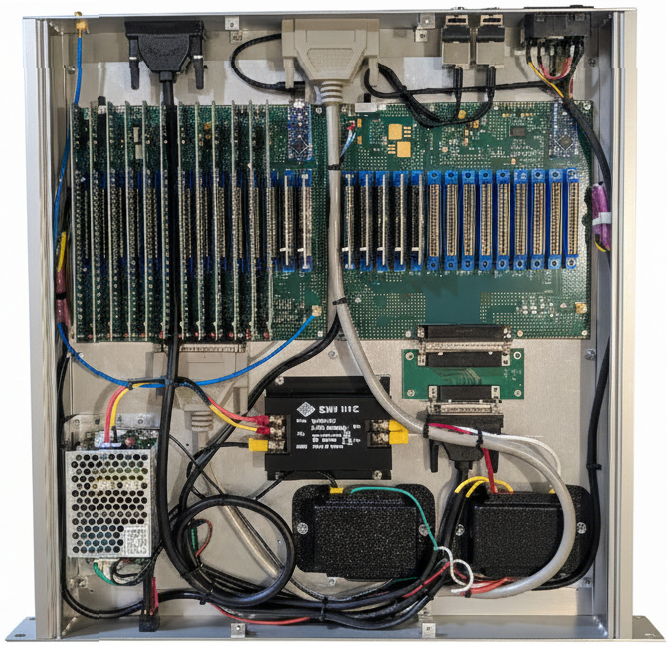
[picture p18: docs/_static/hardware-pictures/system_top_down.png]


    Top down view of the fully assembled TES Bias System.

Step 1
~~~~~~

| Starting with the bottom panel:
| - Place 2mm spacers down onto the M3x10mm and M3x15mm press fit studs.
| - Screw the L-brackets with M3x5mm pan head screws from below.

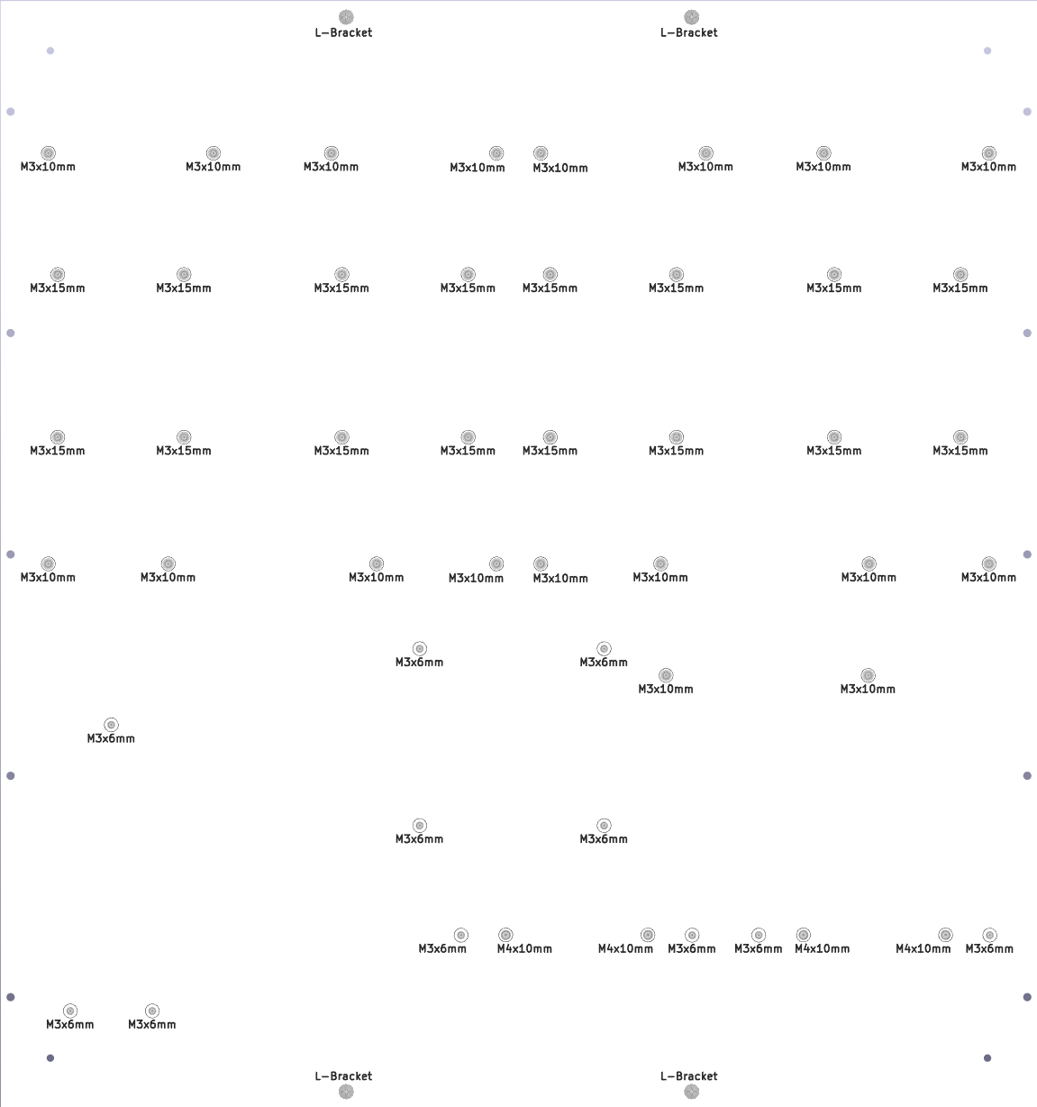
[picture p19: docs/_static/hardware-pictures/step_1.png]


    Top down view of the Bottom Panel.

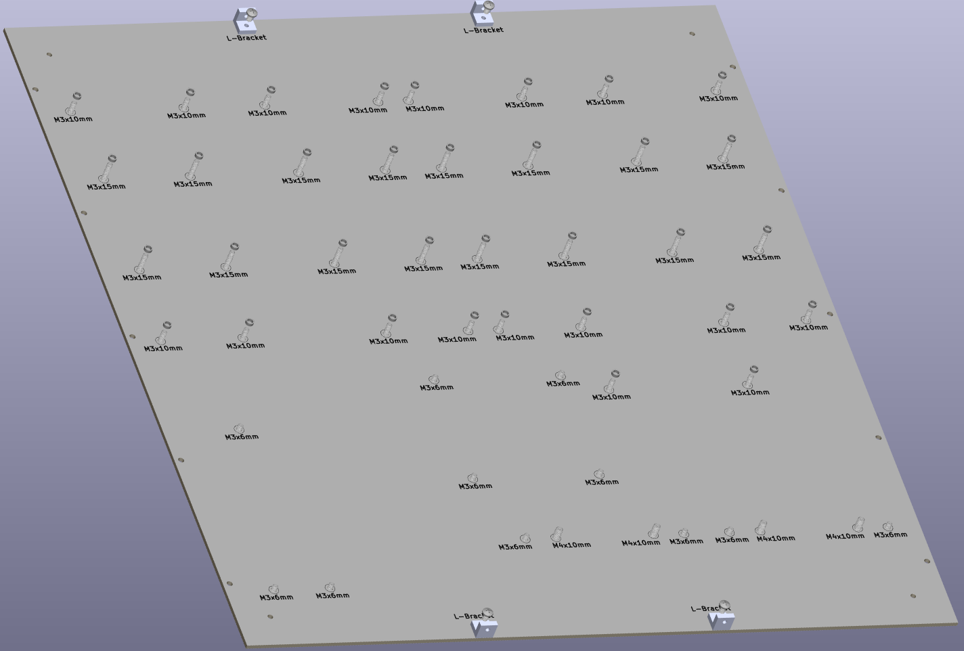
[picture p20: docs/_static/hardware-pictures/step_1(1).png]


    Alternative view of the Bottom Panel.

Step 2
~~~~~~
It's time to place the electronic hardware onto the bottom panel. 
The below pictures illustrate what parts go where. Note that I was 
unable to render the components of the motherboards, power supply and 
line filter, please refer to the `Fully Assembled Enclosure`_ 
image to see what it should look like when the components are placed
properly.

| After Step 1 is complete:
| - Clip the pins of EVERY through-hole component on motherboard and DSUB converter boards without compromising any electrical connections. Note that it is highly suggested to put a 0.2mm thick electrically insulating adhesive pad under every PCB.
| - Place motherboards, `DSUB Converter`_, bus bars, power supply and line filter.
| - Secure every item down with an M3 locknut, except for the bus bars which requires a 94868A038 (M4x6mm female-female) standoff.

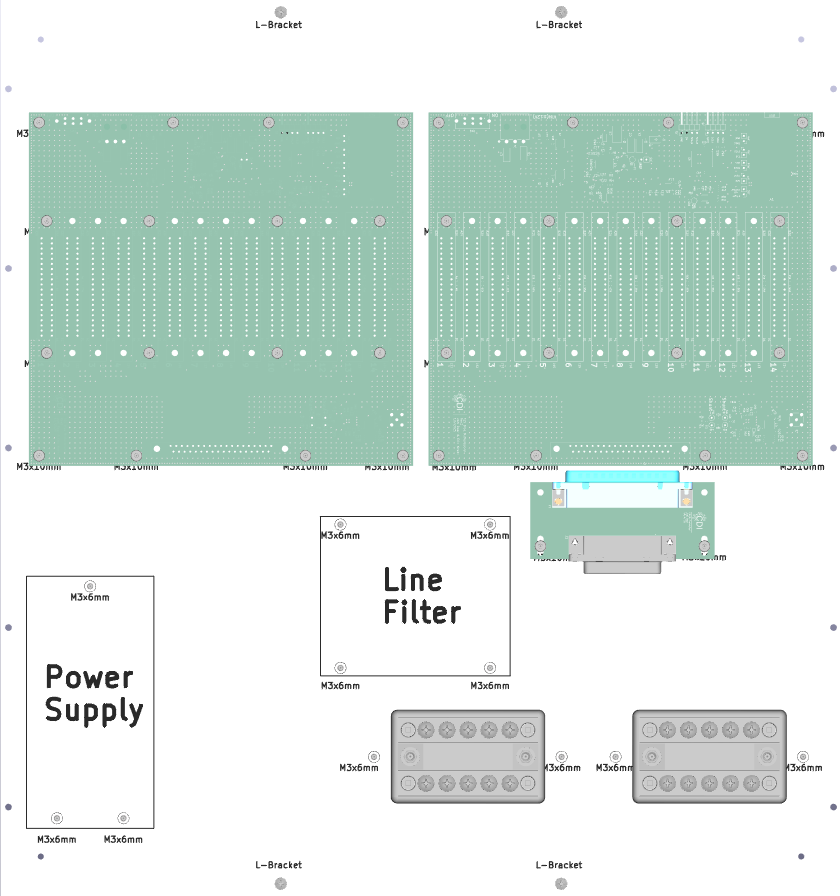
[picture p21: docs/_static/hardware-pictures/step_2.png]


    Electronic hardware installation on the bottom panel.

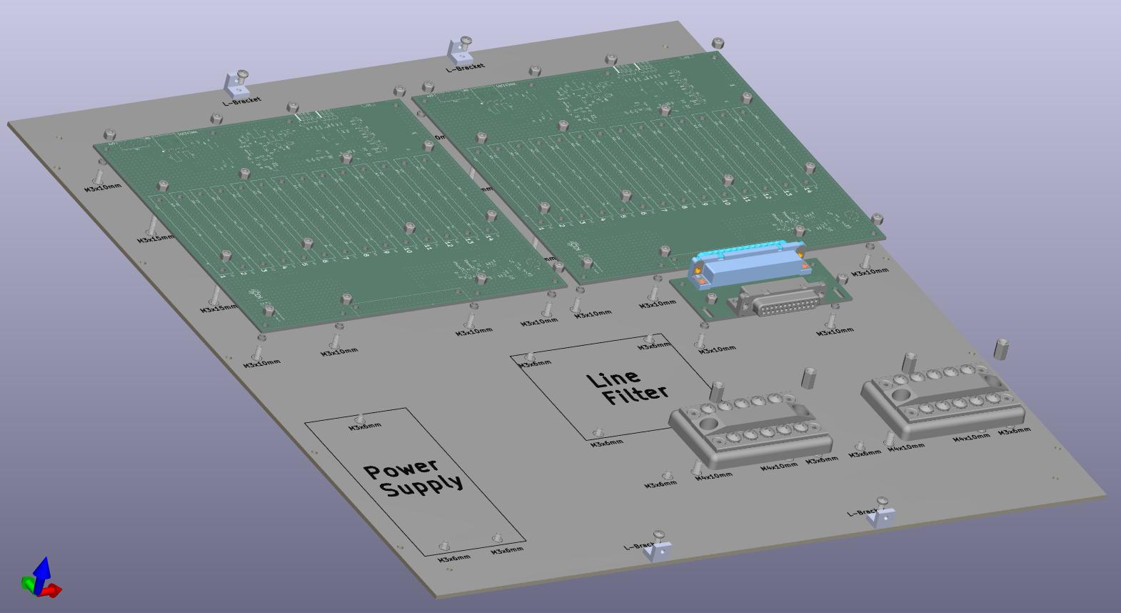
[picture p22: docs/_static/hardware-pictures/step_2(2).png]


    Alternative view of electronic hardware installation on the bottom panel.

Step 3
~~~~~~
Next, we'll secure the Aluminum corner extrusions (G123020_1000) 
to the bottom panel. Note that the below pictures do not have the 
electronic hardware installed, this is just for visual clarity of 
the current step. See the `Bottom Panel`_ section for a note on how
to have the system lay flat on a surface.

| To secure the corner extrusions to the bottom panel:
| - Double check that every electrical component is secured to the bottom panel, because you will turning the assembly on it's side or upside-down for the next steps.
| - Place 10 M3x4mm screws into the unthreaded M3 holes from the bottom (flat side).
| - From the top, screw the square M3 nuts onto the M3x4mm screws but only for 1-2 threads. Take care to ensure that the nuts are threaded the same amount on every screw.
| - Gently place the assembly upside-down, such that the M3x4mm screws lay flush with the back of the bottom panel.
| - Slide the corner extrusion onto the 5 M3 square nuts.

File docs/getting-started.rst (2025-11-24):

Getting Started
===============

This guide walks through core workflows using the TES Controller Python client.

Creating a Controller
---------------------

There are two ways to build a :class:`~tes_controller.controller.DeviceController`.

From a configuration file
~~~~~~~~~~~~~~~~~~~~~~~~~

.. code-block:: python

   from tes_controller import DeviceController

   ctrl = DeviceController.from_config('python/config.yaml')

Direct instantiation
~~~~~~~~~~~~~~~~~~~~

.. code-block:: python

   from tes_controller import DeviceController

   ctrl = DeviceController(
       port='/dev/ttyACM0',
       baud=115200,
       timeout=1.0,
       num_tes=6,
       num_lna=6,
   )

Using Context Managers
----------------------

The controller manages a serial connection. Using a ``with`` block ensures ports
close even if an exception occurs:

.. code-block:: python

   from tes_controller import DeviceController

   with DeviceController.from_config('python/config.yaml') as ctrl:
       data = ctrl.tes_get_all(channel=1)
       print(data)

Channel Selection Patterns
--------------------------

Most high-level helpers accept flexible channel selectors.

Single channel
~~~~~~~~~~~~~~

.. code-block:: python

   ctrl.tes_get_all(channel=1)
   ctrl.tes_set_current(channel=1, current_mA=5.0)
   ctrl.tes_enable(channel=1)

Multiple specific channels
~~~~~~~~~~~~~~~~~~~~~~~~~~

.. code-block:: python

   ctrl.tes_get_all(channel=[1, 3, 5])
   ctrl.tes_set_current(channel=[1, 3, 5], current_mA=5.0)
   ctrl.tes_enable(channel=[1, 3, 5])

All channels
~~~~~~~~~~~~

.. code-block:: python

   ctrl.tes_get_all()
   ctrl.tes_set_current(current_mA=5.0)
   ctrl.tes_enable()

Per-channel values
~~~~~~~~~~~~~~~~~~

Provide a list whose length matches ``num_tes`` (or ``num_lna`` for LNA helpers).

.. code-block:: python

   ctrl.tes_set_current(current_mA=[1.0, 2.0, 3.0, 4.0, 5.0, 6.0])
   ctrl.tes_set_current(channel=[1, 3, 5], current_mA=[1.0, 2.0, 3.0])

TES Operations
--------------

Getters
~~~~~~~

.. code-block:: python

   ctrl.tes_get_all(channel=1)
   ctrl.tes_get_current(channel=1)
   ctrl.tes_get_power(channel=1)
   ctrl.tes_get_shunt(channel=1)
   ctrl.tes_get_bus(channel=1)
   ctrl.tes_get_bits(channel=1)

Setters
~~~~~~~

.. code-block:: python

   ctrl.tes_set_current(channel=1, current_mA=5.0)
   ctrl.tes_set_bits(channel=1, value=0x80000)
   ctrl.tes_inc_current(channel=1, delta=100)
   ctrl.tes_dec_current(channel=1, delta=50)

Enable/Disable
~~~~~~~~~~~~~~

.. code-block:: python

   ctrl.tes_enable(channel=1)
   ctrl.tes_disable(channel=1)
   ctrl.tes_enable()
   ctrl.tes_disable()

LNA Operations
--------------

Target selection
~~~~~~~~~~~~~~~~

Pass ``target='GATE'`` or ``target='DRAIN'`` with every LNA call.

.. code-block:: python

   ctrl.lna_get_all(channel=1, target='GATE')
   ctrl.lna_get_current(channel=1, target='DRAIN')

Setting DAC values
~~~~~~~~~~~~~~~~~~

``lna_set_dac`` accepts raw DAC codes (``0`` – ``0xFFFF``) or physical values. When
you provide a float, the driver performs the conversion and applies the proper
hardware polarity, so pass positive numbers even for gate voltages.

.. code-block:: python

   ctrl.lna_set_dac(channel=1, target='GATE', value=0x8000)
   ctrl.lna_set_dac(channel=1, target='GATE', value=1.2)  # volts/mA
   ctrl.lna_set_dac(target='GATE', value=[1.0, 1.1, 1.2, 1.3, 1.4, 1.5])

Convenience setters
~~~~~~~~~~~~~~~~~~~

The high-level controller forwards convenience wrappers to per-channel drivers.

.. code-block:: python

   ctrl.lna_set_voltage(channel=1, target='GATE', voltage_V=1.2)
   ctrl.lna_set_current(target='GATE', current_mA=[0.5, 1.0, 1.5, 2.0, 2.5, 3.0])

DAC Operations
--------------

The global flux ramp DAC does not use channel selectors.

.. code-block:: python

   ctrl.flux_ramp_set(0x8000)
   ctrl.flux_ramp_get()

Error Handling
--------------

.. code-block:: python

   from tes_controller import DeviceController
   from tes_controller.drivers import CommandError

   with DeviceController.from_config('python/config.yaml') as ctrl:
       try:
           data = ctrl.tes_get_all(channel=1)
       except CommandError as exc:
           print(f"Hardware command failed: {exc}")
       except ValueError as exc:
           print(f"Invalid parameter: {exc}")

Direct Controller Access
------------------------

For repeated operations against a single channel, keep a reference to the
underlying driver instance.

.. code-block:: python

   tes1 = ctrl.get_tes_controller(channel=1)
   tes1.enable()
   tes1.set_current(current_mA=5.0)
   data = tes1.get_all()

Return Types
------------

Single-channel helpers return a single ``dict``. Multi-channel helpers return a
list of ``dict`` objects, one per channel.

Next Steps
----------

- Continue to :doc:`usage` for workflow recipes
- Explore :doc:`examples` for complete scripts
- Read :doc:`api` for full reference material

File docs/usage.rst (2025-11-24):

Usage Guide
===========

Installation
------------

Install the library and its dependencies into your environment:

.. code-block:: bash

   pip install -r python/requirements.txt

Quick Start
-----------

Create a controller from a YAML configuration file:

.. code-block:: python

   from tes_controller import DeviceController

    with DeviceController.from_config("python/config.yaml") as ctrl:
       ctrl.tes_set_current(channel=1, current_mA=5.0)
       reading = ctrl.tes_get_all(channel=1)
       print(reading)

Construct the controller manually when you want to override serial settings:

.. code-block:: python

   from tes_controller import DeviceController

   ctrl = DeviceController(
       port="/dev/ttyACM0",
       baud=115200,
       timeout=1.0,
       num_tes=6,
       num_lna=6,
   )

   try:
       ctrl.tes_enable(channel=[1, 2, 3])
       ctrl.tes_set_current(channel=[1, 2, 3], current_mA=[5.0, 4.5, 4.0])
   finally:
       ctrl.close()

Configuration File
------------------

The helper :meth:`tes_controller.controller.DeviceController.from_config`
method reads a YAML file with the following keys:

.. code-block:: yaml

   port: /dev/ttyACM0
   baud: 115200
   timeout: 1.0
   num_tes: 6
   num_lna: 6

Only the values you need to override are required. Missing values fall back to
sensible defaults.

Channel Selection Patterns
--------------------------

The high-level helpers accept flexible selectors so you can address a single
channel, an explicit subset, or the entire bank with the same call signature.

=============================== =============================================================== ==================
Call                             Effect                                                            Return Type
=============================== =============================================================== ==================
``ctrl.tes_get_all(channel=1)``  Query a single TES channel                                         ``dict``
``ctrl.tes_get_all()``           Query every TES channel                                            ``list[dict]``
``ctrl.tes_set_current(5.0)``    Apply the same current to every TES channel                        ``list[dict]``
``ctrl.tes_set_current(channel=[1, 3], current_mA=[1.0, 2.0])``  Pair channel list with value list  ``list[dict]``
=============================== =============================================================== ==================

See :doc:`getting-started` for a deeper walk-through of these patterns.

Frequently Used Helpers
-----------------------

TES control
~~~~~~~~~~~

.. code-block:: python

    ctrl.tes_get_current(channel=1)
    ctrl.tes_set_current(channel=1, current_mA=5.0)
    ctrl.tes_inc_current(channel=1, delta=100)
    ctrl.tes_enable(channel=[1, 2, 3])
    ctrl.tes_disable()

LNA control
~~~~~~~~~~~

Always include ``target='GATE'`` or ``target='DRAIN'``.

.. code-block:: python

    ctrl.lna_set_dac(channel=1, target='GATE', value=0x8000)
    ctrl.lna_set_dac(channel=1, target='GATE', value=1.2)  # physical units
    ctrl.lna_set_voltage(channel=1, target='GATE', voltage_V=1.2)
    ctrl.lna_enable(target='GATE')

Global DAC
~~~~~~~~~~

.. code-block:: python

    ctrl.flux_ramp_set(0x8000)
    ctrl.flux_ramp_get()

More comprehensive scripts are available in :doc:`examples`.

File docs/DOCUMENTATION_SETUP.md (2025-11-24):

# Documentation Setup Guide ✅

## Contents

- `docs/conf.py` – Sphinx configuration (Read the Docs theme, type hints)
- `docs/index.rst` – Landing page and table of contents
- `docs/installation.rst` – Platform-specific install notes
- `docs/getting-started.rst` – Core usage walkthrough
- `docs/usage.rst` – Quick recipes and configuration snippets
- `docs/examples.rst` – End-to-end scripts
- `docs/api.rst` – Auto-generated API reference
- `docs/Makefile` / `docs/make.bat` – Convenience build targets
- `docs/requirements.txt` – Documentation dependencies
- `docs/.nojekyll` – Allows nested assets for GitHub Pages
- `docs/README.md` – Build and deploy instructions

## Build Locally

```bash
pip install -r docs/requirements.txt
make -C docs html
open docs/_build/html/index.html  # macOS
```

For live reload while editing:

```bash
pip install sphinx-autobuild
sphinx-autobuild docs docs/_build/html
```

## Publish Options

### GitHub Pages

1. Enable Pages for the repository using the `docs/` folder as the source.
2. Copy the freshly built HTML artefacts into `docs/` (or automate via GitHub Actions).
3. Commit and push – GitHub Pages redeploys automatically.

### Read the Docs (optional)

1. Sign in at <https://readthedocs.org/> using GitHub.
2. Import the repository; the builder detects `docs/conf.py` automatically.
3. Configure Python 3.11 (or your preferred version) and trigger a build.

## Updating the Docs

- Update Python docstrings → rebuild to refresh `api.rst` output.
- Add a new page → create `docs/new-page.rst`, link it from `index.rst`, rebuild.
- Ship new examples → edit `docs/examples.rst` and ensure snippets still run.

## Troubleshooting

| Issue | Fix |
|---|-----|
| `ModuleNotFoundError: tes_controller` | Confirm `sys.path.insert` call in `conf.py` and run from repo root |
| Sphinx build warnings | Run `make -C docs clean html` and inspect the warning list |
| GitHub Pages missing CSS/JS | Ensure `.nojekyll` exists in `docs/` and assets were copied |

---

Your documentation stack is ready – build, review, and publish with confidence! 🎉

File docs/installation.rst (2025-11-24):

Installation
============

Requirements
------------

- Python 3.8 or newer
- Serial port access for hardware communication

Install from Source
-------------------

1. Clone the repository:

.. code-block:: bash

   git clone https://github.com/CustomDI/TES_Controller.git
   cd TES_Controller

2. Install the runtime dependencies:

.. code-block:: bash

   pip install -r python/requirements.txt

3. (Optional) Install the documentation toolchain:

.. code-block:: bash

   pip install -r docs/requirements.txt

Configuration
-------------

1. Copy the example configuration file:

.. code-block:: bash

   cp python/config_example.yaml python/config.yaml

2. Edit ``python/config.yaml`` with your serial port settings:

.. code-block:: yaml

   port: /dev/ttyACM0  # Your serial port
   baud: 115200
   timeout: 1.0
   num_tes: 6
   num_lna: 6

Serial Port Notes
-----------------

macOS
~~~~~

Serial ports typically appear as ``/dev/tty.usbmodem*`` or ``/dev/tty.usbserial*``. To list devices:

.. code-block:: bash

   ls /dev/tty.*

Linux
~~~~~

Common serial devices are ``/dev/ttyACM0`` and ``/dev/ttyUSB0``. To list them:

.. code-block:: bash

   ls /dev/ttyACM* /dev/ttyUSB*

If required, add your user to the ``dialout`` group and log out/in:

.. code-block:: bash

   sudo usermod -a -G dialout "$USER"

Windows
~~~~~~~

Serial ports are named ``COM1``, ``COM2`` and so on. Check the Device Manager to find the active COM port.

Verifying Installation
----------------------

Run the bundled example to confirm connectivity:

.. code-block:: bash

   cd python
   python example.py

If the port is configured correctly, you should see YAML responses echoed to the console.

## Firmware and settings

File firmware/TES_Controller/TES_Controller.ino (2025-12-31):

#include <StaticSerialCommands.h>

#include "src/drivers/LTC4302.h"
#include "src/drivers/MCP4728.h"
#include "src/drivers/INA228.h" // Include the INA228 header
#include "src/routers/Router.h" // Include the Router header
#include "src/devices/LNADriver.h" // Include the LNADriver header
#include "src/devices/TESDriver.h" // Include the TESDriver header


// Define I2C addresses for the devices
#define BASE_HUB_LTC4302_ADDR 0x7E // Address for the base hub LTC4302
#define BASE_HUB_MCP4728_ADDR 0x61 // Address for the main MCP4728

// Make TES/LNA counts configurable in one place
#define NUM_TES 12
#define NUM_LNA 2

// Default address lists (easy to edit / override)
const uint8_t DEFAULT_TES_ADDRESSES[NUM_TES] = {
        0x72, 0x62, 0x63, 0x64, 0x65, 0x66,
        0x67, 0x68, 0x69, 0x6A, 0x6B, 0x6C
};

const uint8_t DEFAULT_LNA_ADDRESSES[NUM_LNA] = {
        0x6D, 0x6E
};

// Base hub (unchanged)
LTC4302 baseHub(BASE_HUB_LTC4302_ADDR);

// Router uses baseHub
Router router(&baseHub);

// Route for main MCP4728 (Base Hub -> MCP4728)
I2CRoute routeToMainMCP4728 = { &baseHub, nullptr };
MCP4728 mainDac(BASE_HUB_MCP4728_ADDR);

// Use pointer arrays so the active count can vary at runtime/compile-time
LTC4302* tesLTC[NUM_TES];
TESDriver* tesDriver[NUM_TES];

LTC4302* lnaLTC[NUM_LNA];
LNADriver* lnaDriver[NUM_LNA];

// ----- Command definitions -----------------------------------------------------------
constexpr auto lnaChanArg =
    ARG(ArgType::Int, 1, NUM_LNA, "CHANNEL");

constexpr auto tesChanArg =
    ARG(ArgType::Int, 1, NUM_TES, "CHANNEL");

constexpr auto lnaDrainGate = 
    ARG(ArgType::String, "DRAIN|GATE");

constexpr auto lnaCurrentArg = 
    ARG(ArgType::Float, 0, 64, "CURRENT");

constexpr auto lnaVoltageArg = 
    ARG(ArgType::Float, 0, 5, "VOLTAGE");

constexpr auto dacValueArg =
    ARG(ArgType::Int, 0, 4095, "VALUE");

constexpr auto mainDacValueArg =
    ARG(ArgType::Int, 0, 1024, "VALUE");

constexpr auto tesTCAArg = 
    ARG(ArgType::Int, 0, 0xFFFFF, "BITS"); // 20 bits for TES TCA

constexpr auto tesTCAHexArg = 
    ARG(ArgType::String, "HEXSTRING"); // Hex string for TES TCA

constexpr auto tcaCurrentArg = 
    ARG(ArgType::Float, 0, 20, "CURRENT");

constexpr auto delayMsArg = 
    ARG(ArgType::Int, 0, 10000, "DELAY_MS");

void cmdLNA(SerialCommands& sender, Args& args);
void cmdTES(SerialCommands& sender, Args& args);

void cmdDAC(SerialCommands& sender, Args& args);
void cmdDACSet(SerialCommands& sender, Args& args);
void cmdDACGet(SerialCommands& sender, Args& args);

void cmdLNAGetAll(SerialCommands& sender, Args& args);
void cmdLNASetCurrent(SerialCommands& sender, Args& args);
void cmdLNASetVoltage(SerialCommands& sender, Args& args);
void cmdLNASetDac(SerialCommands& sender, Args& args);
void cmdLNAShunt(SerialCommands& sender, Args& args);
void cmdLNABus(SerialCommands& sender, Args& args);
void cmdLNACurrent(SerialCommands& sender, Args& args);
void cmdLNAPower(SerialCommands& sender, Args& args);
void cmdLNAEnable(SerialCommands& sender, Args& args);
void cmdLNADisable(SerialCommands& sender, Args& args);

void cmdTESGetAll(SerialCommands& sender, Args& args);
void cmdTESSet(SerialCommands& sender, Args& args);
void cmdTESSetInt(SerialCommands& sender, Args& args);
void cmdTESSetHex(SerialCommands& sender, Args& args);
void cmdTESBits(SerialCommands& sender, Args& args);
void cmdTESEnable(SerialCommands& sender, Args& args);
void cmdTESDisable(SerialCommands& sender, Args& args);
void cmdTESInc(SerialCommands& sender, Args& args);
void cmdTESDec(SerialCommands& sender, Args& args);
void cmdTESShunt(SerialCommands& sender, Args& args);
void cmdTESBus(SerialCommands& sender, Args& args);
void cmdTESCurrent(SerialCommands& sender, Args& args);
void cmdTESPower(SerialCommands& sender, Args& args);

void cmdHelp(SerialCommands& sender, Args& args);

Command lnaCommands[] = {
    COMMAND(cmdLNAGetAll, "GET", nullptr, "Get All LNA Parameters for Gate/Drain"),
    COMMAND(cmdLNAEnable, "ENABLE", nullptr, "Enable Gate/Drain"),
    COMMAND(cmdLNADisable, "DISABLE", nullptr, "Disable Gate/Drain"),
    COMMAND(cmdLNASetCurrent, "SETMA", lnaCurrentArg, nullptr, "Search and set Gate/Drain DAC Value (mA)"),
    COMMAND(cmdLNASetVoltage, "SETV", lnaVoltageArg, nullptr, "Search and set Gate/Drain DAC Value (V)"),
    COMMAND(cmdLNASetDac, "SETDAC", dacValueArg, nullptr, "Set Gate/Drain DAC Value"),
    COMMAND(cmdLNAShunt, "SHUNT", nullptr, "Get Gate/Drain Shunt Voltage (mV)"),
    COMMAND(cmdLNABus, "BUS", nullptr, "Get Gate/Drain Bus Voltage (V)"),
    COMMAND(cmdLNACurrent, "CURRENT", nullptr, "Get Gate/Drain Current (mA)"),
    COMMAND(cmdLNAPower, "POWER", nullptr, "Get Gate/Drain Power (mW)"),
};

Command tesCommands[] = {
    COMMAND(cmdTESGetAll, "GET", nullptr, "Get All TES Parameters"),
    COMMAND(cmdTESEnable, "ENABLE", nullptr, "Enable TES Outputs"),
    COMMAND(cmdTESDisable, "DISABLE", nullptr, "Disable TES Outputs"),
    COMMAND(cmdTESSet, "SET", tcaCurrentArg, nullptr, "Search and set TES Output Current (mA)"),
    COMMAND(cmdTESSetInt, "SETINT", tesTCAArg, nullptr, "Set TES TCA Output Bits (Integer)"),
    COMMAND(cmdTESSetHex, "SETHEX", tesTCAHexArg, nullptr, "Set TES TCA Output Bits (Hex)"),
    COMMAND(cmdTESBits, "BIT", nullptr, "Get TES TCA Output Bits (Hex)"),
    COMMAND(cmdTESInc, "INC", tesTCAArg, nullptr, "Increase TES TCA Output Bits (Integer)"),
    COMMAND(cmdTESDec, "DEC", tesTCAArg, nullptr, "Decrease TES TCA Output Bits (Integer)"),
    COMMAND(cmdTESShunt, "SHUNT", nullptr, "Get TES Shunt Voltage (mV)"),
    COMMAND(cmdTESBus, "BUS", nullptr, "Get TES Bus Voltage (V)"),
    COMMAND(cmdTESCurrent, "CURRENT", nullptr, "Get TES Current (mA)"),
    COMMAND(cmdTESPower, "POWER", nullptr, "Get TES Power (mW)"),
};

Command dacCommands[] = {
    COMMAND(cmdDACSet, "SET", mainDacValueArg, nullptr, "Set Main DAC Value"),
    COMMAND(cmdDACGet, "GET", nullptr, "Get Main DAC Value"),
};

Command commands[] = {
    COMMAND(cmdLNA, "LNA", lnaChanArg, lnaDrainGate, lnaCommands, "LNA Commands"),
    COMMAND(cmdTES, "TES", tesChanArg, tesCommands, "TES Commands"),
    COMMAND(cmdDAC, "DAC", dacCommands, "DAC Commands"),
    COMMAND(cmdHelp, "HELP", nullptr, "List All Commands"),
};

SerialCommands serialCommands(Serial, commands, sizeof(commands) / sizeof(Command));


// Helper to initialize devices (call early in setup before begin() calls)
void initDeviceArrays() {
    // Initialize TES LTC4302s and TESDrivers
    for (int i = 0; i < NUM_TES; ++i) {
            uint8_t addr = DEFAULT_TES_ADDRESSES[i];
            tesLTC[i] = new LTC4302(addr);
            tesDriver[i] = new TESDriver(tesLTC[i], &router);
    }

    // Initialize LNA LTC4302s and LNADrivers
    for (int i = 0; i < NUM_LNA; ++i) {
            uint8_t addr = DEFAULT_LNA_ADDRESSES[i];
            lnaLTC[i] = new LTC4302(addr);
            lnaDriver[i] = new LNADriver(lnaLTC[i], &router);
    }
}

// Helper to print out 0 padded hex values
String toPaddedHex(uint32_t value, uint8_t width) {
    String hexStr = String(value, HEX);
    while (hexStr.length() < width) {
        hexStr = "0" + hexStr;
    }
    hexStr.toUpperCase();
    return hexStr;
}

// --- YAML response helpers -------------------------------------------------
String yamlEscape(const String &s) {
    String out = s;
    out.replace("\\", "\\\\");
    out.replace("\"", "\\\"");
    return out;
}

void printIndent(Stream &s, int indent) {
    for (int i = 0; i < indent; ++i) s.print(' ');
}

void printYAMLKeyValue(Stream &s, const char *key, const String &value, int indent = 2, bool quote = true) {
    printIndent(s, indent);
    s.print(key);
    s.print(": ");
    if (quote) {
        s.print('"');
        s.print(yamlEscape(value));
        s.print('"');
        s.println();
    } else {
        s.println(value);
    }
}

void printYAMLHeader(Stream &s, const char *status) {
    s.println("---");
    s.print("status: ");
    s.println(status);
    s.println("result:");
}

// convenience to finish a response with an optional human message key
void printYAMLMessage(Stream &s, const String &message) {
    if (message.length()) {
        printYAMLKeyValue(s, "message", message, 2, true);
    }
    s.println();
}

bool reportIfError(SerialCommands& sender, uint8_t status, const char* errKey, const char* message) {
    if (status) {
        Stream &out = sender.getSerial();
        printYAMLHeader(out, "error");
        printYAMLKeyValue(out, "error", String(errKey), 2, true);
        // include numeric status code for easier debugging
        printYAMLKeyValue(out, "code", String(status), 2, false);
        printYAMLMessage(out, String(message));
        return true;
    }
    return false;
}

void reportError(SerialCommands& sender, const char* errKey, const char* message) {
    Stream &out = sender.getSerial();
    printYAMLHeader(out, "error");
    printYAMLKeyValue(out, "error", String(errKey), 2, true);
    printYAMLMessage(out, String(message));
}

// ---------------------------------------------------------------------------

void setup() {
    Serial.begin(115200);
    Serial.println("TES Controller Starting...");

    initDeviceArrays();
    uint8_t status;

    status = router.begin();
    if (status) {
        Serial.println("Error initializing Base Hub LTC4302");
    }    

    status = baseHub.enableBus();
    if (status) {
        Serial.println("Error enabling I2C bus on Base Hub LTC4302");
    }

    status = mainDac.begin();
    if (status) {
        Serial.println("Error initializing Main MCP4728 DAC");
    }

    // Initialize TESs
    for (int i = 0; i < NUM_TES; ++i) {
        status = tesDriver[i]->begin();
        if (status) {
            Serial.print("Error initializing TES Driver for channel "); Serial.print(i + 1); Serial.print(" with status "); Serial.println(status);
        }
    }
    // Initialize LNAs
    for (int i = 0; i < NUM_LNA; ++i) {
        status = lnaDriver[i]->begin();
        if (status) {
            Serial.print("Error initializing LNA Driver for channel "); Serial.println(i + 1);
        }
    }

    // mainDac.writeDAC(MCP4728_CHANNEL_A, 1024); // Set channel A to ~1/4-scale (4095 max)
    Serial.println("Initialization complete.");
}

void loop() {
    serialCommands.readSerial();
}

void cmdHelp(SerialCommands& sender, Args& args) {
    sender.listAllCommands(commands, sizeof(commands) / sizeof(Command));
}

void cmdLNA(SerialCommands& sender, Args& args) {
    sender.listAllCommands(lnaCommands, sizeof(lnaCommands) / sizeof(Command));
}

void cmdTES(SerialCommands& sender, Args& args) {
    sender.listAllCommands(tesCommands, sizeof(tesCommands) / sizeof(Command));
}

void cmdDAC(SerialCommands& sender, Args& args) {
    sender.listAllCommands(dacCommands, sizeof(dacCommands) / sizeof(Command));
}

void cmdDACSet(SerialCommands& sender, Args& args) {
    uint16_t value = args[0].getInt();
    uint8_t status;
    // Implement setting main DAC value

    status = mainDac.writeDAC(MCP4728_CHANNEL_A, value + 1500, false);
    if (reportIfError(sender, status, "DAC_SET_ERROR", "Failed to set main DAC value.")) {
        return;
    }
    Stream &out = sender.getSerial();
    printYAMLHeader(out, "ok");
    printYAMLKeyValue(out, "command", "DAC_SET", 2, true);
    printYAMLKeyValue(out, "value", String(value), 2, false);
    printYAMLMessage(out, "Main DAC value set");
}

void cmdDACGet(SerialCommands& sender, Args& args) {
    uint16_t value;
    uint8_t status;
    // Implement getting main DAC value
    status = mainDac.readDAC(MCP4728_CHANNEL_A, value);
    if (reportIfError(sender, status, "DAC_GET_ERROR", "Failed to get main DAC value.")) {
        return;
    }
    Stream &out = sender.getSerial();
    printYAMLHeader(out, "ok");
    printYAMLKeyValue(out, "command", "DAC_GET", 2, true);
    printYAMLKeyValue(out, "value", String(value), 2, false);
    printYAMLMessage(out, "Main DAC value retrieved");
}
void cmdLNASetCurrent(SerialCommands& sender, Args& args) {
    uint8_t channel = args[0].getInt() - 1;
    const char* target = args[1].getString();
    float target_mA = args[2].getFloat();
    uint16_t dacValue;
    uint8_t status;
    if (strcmp(target, "DRAIN") == 0) {
        status = lnaDriver[channel]->setDrainCurrent(target_mA, dacValue, 1);
        if (reportIfError(sender, status, "LNA_SET_ERROR", "Failed to set Drain current.")) {
            return;
        }
    } else if (strcmp(target, "GATE") == 0) {
        status = lnaDriver[channel]->setGateCurrent(target_mA, dacValue, 1);
        if (reportIfError(sender, status, "LNA_SET_ERROR", "Failed to set Gate current.")) {
            return;
        }    } else {
        reportError(sender, "Invalid target. Use DRAIN or GATE.", "Invalid target");
    }
    Stream &out = sender.getSerial();
    printYAMLHeader(out, "ok");
    printYAMLKeyValue(out, "command", "LNA_SET", 2, true);
    printYAMLKeyValue(out, "channel", String(channel + 1), 2, false);
    printYAMLKeyValue(out, "target", target, 2, true);
    printYAMLKeyValue(out, "current_mA", String(target_mA, 7), 2, false);
    printYAMLKeyValue(out, "dac_value", String(dacValue), 2, false);
    printYAMLMessage(out, "LNA current set");
}

void cmdLNASetVoltage(SerialCommands& sender, Args& args) {
    uint8_t channel = args[0].getInt() - 1;
    const char* target = args[1].getString();
    float target_V = args[2].getFloat();
    uint16_t dacValue;
    uint8_t status;
    if (strcmp(target, "DRAIN") == 0) {
        status = lnaDriver[channel]->setDrainVoltage(target_V, dacValue, 1);
        if (reportIfError(sender, status, "LNA_SET_ERROR", "Failed to set Drain voltage.")) {
            return;
        }
    } else if (strcmp(target, "GATE") == 0) {
        status = lnaDriver[channel]->setGateVoltage(target_V, dacValue, 1);
        if (reportIfError(sender, status, "LNA_SET_ERROR", "Failed to set Gate voltage.")) {
            return;
        }    } else {
        reportError(sender, "Invalid target. Use DRAIN or GATE.", "Invalid target");
    }
    Stream &out = sender.getSerial();
    printYAMLHeader(out, "ok");
    printYAMLKeyValue(out, "command", "LNA_SET", 2, true);
    printYAMLKeyValue(out, "channel", String(channel + 1), 2, false);
    printYAMLKeyValue(out, "target", target, 2, true);
    printYAMLKeyValue(out, "voltage_V", String(target_V, 7), 2, false);
    printYAMLKeyValue(out, "dac_value", String(dacValue), 2, false);
    printYAMLMessage(out, "LNA voltage set");
}

void cmdLNASetDac(SerialCommands& sender, Args& args) {
    uint8_t channel = args[0].getInt() - 1;
    const char* target = args[1].getString();
    uint16_t value = args[2].getInt();
    uint8_t status;
    if (strcmp(target, "DRAIN") == 0) {
        status = lnaDriver[channel]->writeDrain(value);
        if (reportIfError(sender, status, "LNA_SET_ERROR", "Failed to set Drain DAC value.")) {
            return;
        }
        Stream &out = sender.getSerial();
        printYAMLHeader(out, "ok");
        printYAMLKeyValue(out, "command", "LNA_SET", 2, true);
        printYAMLKeyValue(out, "channel", String(channel + 1), 2, false);
        printYAMLKeyValue(out, "target", "DRAIN", 2, true);
        printYAMLKeyValue(out, "value", String(value), 2, false);
        printYAMLMessage(out, "LNA DRAIN DAC value set");
    } else if (strcmp(target, "GATE") == 0) {
        status = lnaDriver[channel]->writeGate(value);
        if (reportIfError(sender, status, "LNA_SET_ERROR", "Failed to set Gate DAC value.")) {
            return;
        }
        Stream &out = sender.getSerial();
        printYAMLHeader(out, "ok");
        printYAMLKeyValue(out, "command", "LNA_SET", 2, true);
        printYAMLKeyValue(out, "channel", String(channel + 1), 2, false);
        printYAMLKeyValue(out, "target", "GATE", 2, true);
        printYAMLKeyValue(out, "value", String(value), 2, false);
        printYAMLMessage(out, "LNA GATE DAC value set");
    } else {
        reportError(sender, "Invalid target. Use DRAIN or GATE.", "Invalid target");
    }
}

void cmdLNAShunt(SerialCommands& sender, Args& args) {
    uint8_t channel = args[0].getInt() - 1;
    const char* target = args[1].getString();
    float shuntVoltage;
    uint8_t status;
    if (strcmp(target, "DRAIN") == 0) {
        status = lnaDriver[channel]->getDrainShuntVoltage_mV(shuntVoltage);
        if (reportIfError(sender, status, "LNA_SHUNT_READ_ERROR", "Failed to read Drain shunt voltage.")) {
            return;
        }
        Stream &out = sender.getSerial();
        printYAMLHeader(out, "ok");
        printYAMLKeyValue(out, "command", "LNA_SHUNT", 2, true);
        printYAMLKeyValue(out, "channel", String(channel + 1), 2, false);
        printYAMLKeyValue(out, "target", "DRAIN", 2, true);
        printYAMLKeyValue(out, "shunt_mV", String(shuntVoltage, 7), 2, false);
        printYAMLMessage(out, "Drain shunt voltage (mV)");
    } else if (strcmp(target, "GATE") == 0) {
        status = lnaDriver[channel]->getGateShuntVoltage_mV(shuntVoltage);
        if (reportIfError(sender, status, "LNA_SHUNT_READ_ERROR", "Failed to read Gate shunt voltage.")) {
            return;
        }
        Stream &out = sender.getSerial();
        printYAMLHeader(out, "ok");
        printYAMLKeyValue(out, "command", "LNA_SHUNT", 2, true);
        printYAMLKeyValue(out, "channel", String(channel + 1), 2, false);
        printYAMLKeyValue(out, "target", "GATE", 2, true);
        printYAMLKeyValue(out, "shunt_mV", String(shuntVoltage, 7), 2, false);
        printYAMLMessage(out, "Gate shunt voltage (mV)");
    } else {
        reportError(sender, "Invalid target. Use DRAIN or GATE.", "Invalid target");
    }
}

void cmdLNABus(SerialCommands& sender, Args& args) {
    uint8_t channel = args[0].getInt() - 1;
    const char* target = args[1].getString();
    float busVoltage;
    uint8_t status;
    if (strcmp(target, "DRAIN") == 0) {
        status = lnaDriver[channel]->getDrainBusVoltage_V(busVoltage);
        if (reportIfError(sender, status, "LNA_BUS_READ_ERROR", "Failed to read Drain bus voltage.")) {
            return;
        }
        Stream &out = sender.getSerial();
        printYAMLHeader(out, "ok");
        printYAMLKeyValue(out, "command", "LNA_BUS", 2, true);
        printYAMLKeyValue(out, "channel", String(channel + 1), 2, false);
        printYAMLKeyValue(out, "target", "DRAIN", 2, true);
        printYAMLKeyValue(out, "bus_V", String(busVoltage, 7), 2, false);
        printYAMLMessage(out, "Drain bus voltage (V)");
    } else if (strcmp(target, "GATE") == 0) {
        status = lnaDriver[channel]->getGateBusVoltage_V(busVoltage);
        if (reportIfError(sender, status, "LNA_BUS_READ_ERROR", "Failed to read Gate bus voltage.")) {
            return;
        }
        Stream &out = sender.getSerial();
        printYAMLHeader(out, "ok");
        printYAMLKeyValue(out, "command", "LNA_BUS", 2, true);
        printYAMLKeyValue(out, "channel", String(channel + 1), 2, false);
        printYAMLKeyValue(out, "target", "GATE", 2, true);
        printYAMLKeyValue(out, "bus_V", String(busVoltage, 7), 2, false);
        printYAMLMessage(out, "Gate bus voltage (V)");
    } else {
        reportError(sender, "Invalid target. Use DRAIN or GATE.", "Invalid target");
    }
}

void cmdLNACurrent(SerialCommands& sender, Args& args) {
    uint8_t channel = args[0].getInt() - 1;
    const char* target = args[1].getString();
    float current;
    uint8_t status;
    if (strcmp(target, "DRAIN") == 0) {
        status = lnaDriver[channel]->getDrainCurrent_mA(current);
        if (reportIfError(sender, status, "LNA_CURRENT_READ_ERROR", "Failed to read Drain current.")) {
            return;
        }
        Stream &out = sender.getSerial();
        printYAMLHeader(out, "ok");
        printYAMLKeyValue(out, "command", "LNA_CURRENT", 2, true);
        printYAMLKeyValue(out, "channel", String(channel + 1), 2, false);
        printYAMLKeyValue(out, "target", "DRAIN", 2, true);
        printYAMLKeyValue(out, "current_mA", String(current, 7), 2, false);
        printYAMLMessage(out, "Drain current (mA)");
    } else if (strcmp(target, "GATE") == 0) {
        status = lnaDriver[channel]->getGateCurrent_mA(current);
        if (reportIfError(sender, status, "LNA_CURRENT_READ_ERROR", "Failed to read Gate current.")) {
            return;
        }
        Stream &out = sender.getSerial();
        printYAMLHeader(out, "ok");
        printYAMLKeyValue(out, "command", "LNA_CURRENT", 2, true);
        printYAMLKeyValue(out, "channel", String(channel + 1), 2, false);
        printYAMLKeyValue(out, "target", "GATE", 2, true);
        printYAMLKeyValue(out, "current_mA", String(current, 7), 2, false);
        printYAMLMessage(out, "Gate current (mA)");
    } else {
        reportError(sender, "Invalid target. Use DRAIN or GATE.", "Invalid target");

    }
}
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

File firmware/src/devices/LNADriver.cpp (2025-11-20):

#include "LNADriver.h"

// The LTC4302 acts as an I2C repeater, not a multiplexer with channels.
// Therefore, internal channel definitions for devices behind it are not needed
// for routing. The MCP4728 still has its own internal channels (A, B, C, D) for
// DAC selection.

LNADriver::LNADriver(LTC4302* lnaLtc4302, Router* router)
    : _lnaLtc4302(lnaLtc4302),
      _router(router),
      _routeToLnaLtc4302({_lnaLtc4302, nullptr}),
      _lnaDac(LNA_MCP4728_ADDR),
      _lnaInaDrain(LNA_INA_DRAIN_ADDR),
      _lnaInaGate(LNA_INA_GATE_ADDR) {
}

uint8_t LNADriver::begin() {
    RETURN_IF_ERROR(_lnaLtc4302->begin());
    RETURN_IF_ERROR(connect());
    RETURN_IF_ERROR(_lnaDac.begin());
    RETURN_IF_ERROR(_lnaInaDrain.begin(LNA_INA_SHUNT_RESISTANCE_OHMS,
                       LNA_INA_MAX_EXPECTED_CURRENT_AMPS));
    RETURN_IF_ERROR(_lnaInaGate.begin(LNA_INA_SHUNT_RESISTANCE_OHMS,
                      LNA_INA_MAX_EXPECTED_CURRENT_AMPS));
    return disconnect();
}

// Methods to interact with the LNA's MCP4728
uint8_t LNADriver::writeDrain(uint16_t value) {
    RETURN_IF_ERROR(connect());
    RETURN_IF_ERROR(_lnaDac.writeDAC(LNA_DRAIN_CHANNEL, value));  // Channel A controls Drain
    return disconnect();
}
uint8_t LNADriver::writeGate(uint16_t value) {
    RETURN_IF_ERROR(connect());
    RETURN_IF_ERROR(_lnaDac.writeDAC(LNA_DRAIN_CHANNEL, value));  // Channel A controls Drain
    return disconnect();
}

uint8_t LNADriver::readDrain(uint16_t& value) { 
    RETURN_IF_ERROR(connect());
    RETURN_IF_ERROR(_lnaDac.readDAC(LNA_DRAIN_CHANNEL, value));
    return disconnect();
}

uint8_t LNADriver::readGate(uint16_t& value) {
    RETURN_IF_ERROR(connect());
    RETURN_IF_ERROR(_lnaDac.readDAC(LNA_GATE_CHANNEL, value));
    return disconnect();
}

uint8_t LNADriver::setDrainCurrent(float& target_mA, uint16_t& dacValue, uint8_t delayMs) {
    if (!(target_mA >= 0.0f && target_mA <= 64.0f)) {
        return 10; // invalid argument
    }
    RETURN_IF_ERROR(connect());
    float readCurrent = 0;
    dacValue = 0;
    while(readCurrent < target_mA && dacValue < 4095) {
        dacValue++;
        RETURN_IF_ERROR(_lnaDac.writeDAC(LNA_DRAIN_CHANNEL, dacValue));
        delay(delayMs); // Allow time for settling
        RETURN_IF_ERROR(_lnaInaDrain.getCurrent_mA(readCurrent));
    }
    dacValue = (dacValue > 0 && dacValue < 4095) ? dacValue - 1 : 0;
    RETURN_IF_ERROR(_lnaDac.writeDAC(LNA_DRAIN_CHANNEL, dacValue));
    RETURN_IF_ERROR(_lnaInaDrain.getCurrent_mA(target_mA));
    return disconnect();
}

uint8_t LNADriver::setGateCurrent(float& target_mA, uint16_t& dacValue, uint8_t delayMs) {
    if (!(target_mA >= 0.0f && target_mA <= 64.0f)) {
        return 10; // invalid argument
    }
    target_mA = -target_mA; // Gate current is negative
    RETURN_IF_ERROR(connect());
    float readCurrent = 0;
    dacValue = 0;
    while(readCurrent > target_mA && dacValue < 4095) {
        dacValue++;
        RETURN_IF_ERROR(_lnaDac.writeDAC(LNA_GATE_CHANNEL, dacValue));
        delay(delayMs); // Allow time for settling
        RETURN_IF_ERROR(_lnaInaGate.getCurrent_mA(readCurrent));
    }
    dacValue = (dacValue > 0 && dacValue < 4095) ? dacValue - 1 : 0;
    RETURN_IF_ERROR(_lnaDac.writeDAC(LNA_GATE_CHANNEL, dacValue));
    RETURN_IF_ERROR(_lnaInaGate.getCurrent_mA(target_mA));
    return disconnect();
}

uint8_t LNADriver::setDrainVoltage(float& target_V, uint16_t& dacValue, uint8_t delayMs) {
    if (!(target_V >= 0.0f && target_V <= 5.0f)) {
        return 10; // invalid argument
    }
    RETURN_IF_ERROR(connect());
    float readVoltage = 0;
    dacValue = 0;
    while(readVoltage < target_V && dacValue < 4095) {
        dacValue++;
        RETURN_IF_ERROR(_lnaDac.writeDAC(LNA_DRAIN_CHANNEL, dacValue));
        delay(delayMs); // Allow time for settling
        RETURN_IF_ERROR(_lnaInaDrain.getBusVoltage_V(readVoltage));
    }
    dacValue = (dacValue > 0 && dacValue < 4095) ? dacValue - 1 : 0;
    RETURN_IF_ERROR(_lnaDac.writeDAC(LNA_DRAIN_CHANNEL, dacValue));
    RETURN_IF_ERROR(_lnaInaDrain.getBusVoltage_V(target_V));
    return disconnect();
}

uint8_t LNADriver::setGateVoltage(float& target_V, uint16_t& dacValue, uint8_t delayMs) {
    if (!(target_V >= 0.0f && target_V <= 5.0f)) {
        return 10; // invalid argument
    }
    RETURN_IF_ERROR(connect());
    float readVoltage = 0;
    dacValue = 0;
    while(readVoltage < target_V && dacValue < 4095) {
        dacValue++;
        RETURN_IF_ERROR(_lnaDac.writeDAC(LNA_GATE_CHANNEL, dacValue));
        delay(delayMs); // Allow time for settling
        RETURN_IF_ERROR(_lnaInaGate.getBusVoltage_V(readVoltage));
    }
    dacValue = (dacValue > 0 && dacValue < 4095) ? dacValue - 1 : 0;
    RETURN_IF_ERROR(_lnaDac.writeDAC(LNA_GATE_CHANNEL, dacValue));
    RETURN_IF_ERROR(_lnaInaGate.getBusVoltage_V(target_V));
    target_V = -target_V; // Gate voltage is negative
    return disconnect();
}

uint8_t LNADriver::getDrainShuntVoltage_mV(float& shuntVoltage) {
    RETURN_IF_ERROR(connect());
    RETURN_IF_ERROR(_lnaInaDrain.getShuntVoltage_mV(shuntVoltage));
    return disconnect();
}

uint8_t LNADriver::getDrainBusVoltage_V(float& busVoltage) {
    RETURN_IF_ERROR(connect());
    RETURN_IF_ERROR(_lnaInaDrain.getBusVoltage_V(busVoltage));
    return disconnect();
}

uint8_t LNADriver::getDrainCurrent_mA(float& current) {
    RETURN_IF_ERROR(connect());
    RETURN_IF_ERROR(_lnaInaDrain.getCurrent_mA(current));
    return disconnect();
}

uint8_t LNADriver::getDrainPower_mW(float& power) {
    RETURN_IF_ERROR(connect());
    RETURN_IF_ERROR(_lnaInaDrain.getPower_mW(power));
    return disconnect();
}

uint8_t LNADriver::getGateShuntVoltage_mV(float& shuntVoltage) {
    RETURN_IF_ERROR(connect());
    RETURN_IF_ERROR(_lnaInaGate.getShuntVoltage_mV(shuntVoltage));
    return disconnect();
}

uint8_t LNADriver::getGateBusVoltage_V(float& busVoltage) {
    RETURN_IF_ERROR(connect());
    RETURN_IF_ERROR(_lnaInaGate.getBusVoltage_V(busVoltage));
    busVoltage = -busVoltage; // Drain voltage is negative
    return disconnect();
}

uint8_t LNADriver::getGateCurrent_mA(float& current) {
    RETURN_IF_ERROR(connect());
    RETURN_IF_ERROR(_lnaInaGate.getCurrent_mA(current));
    return disconnect();
}

uint8_t LNADriver::getGatePower_mW(float& power) {
    RETURN_IF_ERROR(connect());
    RETURN_IF_ERROR(_lnaInaGate.getPower_mW(power));
    return disconnect();
}

uint8_t LNADriver::setGateEnable(
    bool state) {    // False is enable, true is disable
    state = !state;  // Invert state for LTC4302 GPIO logic
    RETURN_IF_ERROR(connect());
    RETURN_IF_ERROR(_lnaLtc4302->setGPIO(1, state));
    return disconnect();
}

uint8_t LNADriver::setDrainEnable(bool state) {
    state = !state;  // Invert state for LTC4302 GPIO logic
    RETURN_IF_ERROR(connect());
    RETURN_IF_ERROR(_lnaLtc4302->setGPIO(2, state));
    return disconnect();
}
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

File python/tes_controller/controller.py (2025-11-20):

import yaml
from typing import Optional, Dict, Any, Union, List
from .serial_client import SerialClient
from .drivers import TesController, LnaController, FluxRampController

class DeviceController:
    """High-level controller that encapsulates SerialClient, TesController and LnaController.

    Usage:
        # from file
        ctrl = DeviceController.from_config('path/to/config.yaml')

        # or construct directly
        ctrl = DeviceController(port='/dev/ttyACM0', baud=115200, timeout=1.0, num_tes=6, num_lna=6)

    The DeviceController exposes:
      - client: SerialClient
      - tes: TesController
      - lna: LnaController
      - num_tes, num_lna

    Note: the underlying drivers are thin wrappers that send commands and parse YAML responses.
    """

    def __init__(self, port: str = '/dev/ttyACM0', baud: int = 115200, timeout: float = 1.0,
                 num_tes: int = 6, num_lna: int = 6, auto_open: bool = True):
        self.port = port
        self.baud = baud
        self.timeout = timeout
        self.num_tes = num_tes
        self.num_lna = num_lna

        self.client = SerialClient(self.port, baud=self.baud, timeout=self.timeout)
        if auto_open:
            self.client.open()

        # Create per-channel controller instances bound to their channel numbers.
        # tes and lna are lists indexed by (channel-1).
        self.tes: List[TesController] = [TesController(self.client, i + 1) for i in range(self.num_tes)]
        self.lna: List[LnaController] = [LnaController(self.client, i + 1) for i in range(self.num_lna)]
        
        # DAC controller (single instance, no channel binding)
        self.dac = FluxRampController(self.client)

    @classmethod
    def from_config(cls, path: str, auto_open: bool = True) -> 'DeviceController':
        """Load controller config from a YAML file.

        Expected keys: port, baud, timeout, num_tes, num_lna
        """
        with open(path, 'r', encoding='utf-8') as f:
            cfg = yaml.safe_load(f) or {}
        port = cfg.get('port', '/dev/ttyACM0')
        baud = cfg.get('baud', 115200)
        timeout = cfg.get('timeout', 1.0)
        num_tes = cfg.get('num_tes', 6)
        num_lna = cfg.get('num_lna', 6)
        return cls(port=port, baud=baud, timeout=timeout, num_tes=num_tes, num_lna=num_lna, auto_open=auto_open)

    def close(self):
        try:
            self.client.close()
        except Exception:
            pass

    def __enter__(self):
        return self

    def __exit__(self, exc_type, exc, tb):
        self.close()

    # ========== DAC Convenience Methods ==========
    def flux_ramp_set(self, value: int) -> Dict[str, Any]:
        """Set DAC value (0-0xFFFF)."""
        return self.dac.set_dac(value)

    def flux_ramp_get(self) -> Dict[str, Any]:
        """Get current DAC value."""
        return self.dac.get_dac()

    # ========== TES Convenience Methods ==========
    def tes_get_all(self, channel: Union[int, List[int], None] = None) -> Union[Dict[str, Any], List[Dict[str, Any]]]:
        """Get all TES channel data.
        
        Args:
            channel: int for single channel, list of ints for multiple, None for all channels
            
        Returns:
            Single dict if channel is int, list of dicts otherwise
        """
        if channel is None:
            return [self.tes[i].get_all() for i in range(self.num_tes)]
        elif isinstance(channel, list):
            return [self.tes[ch - 1].get_all() for ch in channel]
        else:
            self._check_tes_channel(channel)
            return self.tes[channel - 1].get_all()
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

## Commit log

2025-11-17 INA Updated with proper error handling
    [LNADriver.cpp, LTC4302.cpp, Router.cpp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]
2025-11-17 Okay now LTC fixed
    [TESDriver.cpp, TES_Controller.ino]
2025-11-17 ALL ERROR HANDLING HANDLED (except set)
    [TCA642ARGJR.cpp, TESDriver.cpp, TES_Controller.ino]
2025-11-17 Python Drivers
2025-11-18 Add functionality to search for Current/Voltage on LNA
2025-12-15 Added production files and referenced them in the hardware guide
    [HousingProfile2_445mm.step, L-bracket.STEP, SidePanel_1U_445mm.dxf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]
2025-12-15 Reorganized production files, added PCB production files, and updated link in hardware-guide.rst
    [HousingProfile2_445mm.step, L-bracket.STEP, SidePanel_1U_445mm.dxf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]
2025-12-18 resorted systems
    [HousingProfile2_445mm.step, L-bracket.STEP, SidePanel_1U_445mm.dxf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]
2025-12-31 Updated PCB production files
2025-12-31 Pushing with correct device count/config
    [TES_Controller.ino]
